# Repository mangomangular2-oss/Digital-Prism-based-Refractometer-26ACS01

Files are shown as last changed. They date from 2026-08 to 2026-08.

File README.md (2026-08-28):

# A Digital Prism-Based Refractometer

Firmware, CAD, raw data and analysis scripts for a low-cost automated
refractometer, built for the **Singapore Science Mentorship Programme 2026**
(Team 26ACS01).

The instrument measures a liquid's refractive index by finding the **critical
angle** at a prism–liquid interface. A stepper motor sweeps the prism through a
range of angles while a light-dependent resistor records how much light reaches
it; the critical angle is recovered from the steep edge of that signal, and
converted to refractive index on board.

**Team** — Isaac Yong Tze Hsi · Ng Yi-Shen · Shah Prish Vaishal \
**Mentor** — Mr Li Zhen, CRADLE, Science Centre Singapore\
**Teacher advisors** — Mdm Ali Basheera Banu, Mr Alvin Liew Shao Chuan\
**School** — Anglo-Chinese School (Independent), Singapore

## Headline results

| | |
|---|---|
| Mean deviation from reference values, five liquids | 0.18 % |
| Repeatability (standard error of five repeats, in *n*) | ±0.0005 |
| Total build cost | S$291 |
| Range | *n* = 1.000 – 1.498 (upper limit set by the prism's geometry and refractive index) |

## What is in this repository

| Folder | Contents |
|---|---|
| `firmware/` | The Arduino sketch that runs the instrument |
| `hardware/` | 3D-printable parts for the optical head and stage, as well as circuit schematic and total build cost |
| `data/` | Raw measurements, exactly as recorded |
| `analysis/` | Python scripts that turn the data into the paper's figures |
| `docs/` | The research paper and conference poster |

## Reproducing the figures

```bash
pip install numpy matplotlib openpyxl
cd analysis
python3 intensity_profile.py     # the sweep data, and the edge fit
python3 calibration.py           # measured vs accepted refractive index
python3 circuit_schematic.py     # wiring diagram, drawn from the pin map
```

## The main finding

Our first analysis took the **brightest point** of the light curve as the
critical angle. Checked against liquids of known refractive index, that was
wrong by up to 0.025.

The critical angle actually sits on the **steep rising edge** of the curve, at
the half-height point. Read there, the result is correct to 0.003 — about eight
times better. Where the brightest point falls depends on the beam width and the
sensor's position, so it shifts when the stage sweeps the other way; the steep
edge does not. `analysis/intensity_profile.py` shows both, for both sweep
directions.

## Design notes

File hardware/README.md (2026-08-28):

# Hardware

3D-printable parts for the optical head, rotating stage and housing.

Printed in black PLA. The colour matters, as it suppresses stray internal
reflections that otherwise produce false readings.

Circuit schematic for the final product, including an Arduino Uno Microcontroller, ULN2003 Driver Board, 16 x 2 LCD, 4 x 3 keypad, 28BYJ-48 Motor.

Complete bill of materials the final product.

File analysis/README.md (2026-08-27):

# Analysis

Scripts that regenerate the paper's figures from the raw data. Run them from
inside this folder — the data paths are relative.

```bash
pip install numpy matplotlib openpyxl
python3 intensity_profile.py
python3 calibration.py
python3 circuit_schematic.py
```

| Script | Output | What it does |
|---|---|---|
| `intensity_profile.py` | `intensity_profile.png` | Plots both sweep directions, fits the steep edge of each curve and marks the 50 % crossing taken as the critical angle |
| `calibration.py` | `calibration.png` | Measured against accepted refractive index, with the best-fit line and R² |
| `circuit_schematic.py` | `circuit_schematic.png` | Draws the wiring diagram directly from the firmware's pin map |

`intensity_profile.py` prints the recovered critical angle and refractive index
for each liquid and sweep direction, alongside the accepted value, so the
numbers in the paper can be checked against the raw data.

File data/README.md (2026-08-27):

# Data

Raw measurements, exactly as recorded. Nothing here has been corrected or
calibrated.

## `intensity_profiles.xlsx`

624 rows, one per motor half-step, covering a full sweep from a stage angle of
15°. This is the data behind the intensity-profile figure.

| Column | Meaning |
|---|---|
| `step` | Motor half-step number from the start of the sweep |
| `stage_angle_deg` | Stage angle, degrees. `15 + step x 0.0883` |
| `theta_hypotenuse_deg` | The corresponding angle at the prism–liquid interface |
| `A_water_counts` | Light sensor reading, deionised water, clockwise sweep |
| `A_olive_oil_counts` | Light sensor reading, olive oil, clockwise sweep |
| `B_water_counts` | Deionised water, anticlockwise sweep |
| `B_olive_oil_counts` | Olive oil, anticlockwise sweep |

Readings are raw 10-bit ADC counts (0–1023) from the LDR divider on A0.

The two sweep directions are the evidence for the main finding: the steep edge
of the curve lands in almost the same place either way, while the peak does not.

## `measurements.xlsx`

The trial-by-trial workbook behind the paper's tables.

| Sheet | Contents |
|---|---|
| `How to use` | Notes on filling the workbook |
| `T1 raw readings` | Every trial for the five reference liquids |
| `T1 summary` | Means and standard errors, all by formula |
| `T2 sucrose` | Concentration-mode trials, sucrose standards |
| `T3 bill of materials` | Costs, from receipts |
| `Conditions` | Instrument and session conditions |
| `Precision rules` | How many decimal places each quantity is reported to, and why |

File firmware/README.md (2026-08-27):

# Firmware

`refractometer.ino` — the sketch as flashed to the instrument. Arduino Uno.

## Libraries

Install through the Arduino IDE's Library Manager:

- **LiquidCrystal I2C** by Frank de Brabander
- **Keypad** by Mark Stanley / Alexander Brevig

## Pin map

| Pin | Use |
|---|---|
| D2 | MEASURE button (`INPUT_PULLUP`, pressed = LOW) |
| D3 | Mode rocker (`INPUT_PULLUP`, LOW = concentration mode) |
| D4–D7 | Keypad rows |
| D8–D11 | Stepper coils, via ULN2003 driver board |
| D12, D13 | Keypad columns 0, 1 |
| A0 | LDR (light-dependent resistor), in a divider with 10 kΩ |
| A1 | Keypad column 2 |
| A2 | Free |
| A3 | Free — reserved for a DS18B20 temperature sensor |
| A4, A5 | I²C to the LCD backpack (address 0x27) |

The 589 nm laser is powered from the 5 V rail and is not switched by the
microcontroller.

## Two modes

- **Rocker HIGH** — a single refractive-index measurement.
- **Rocker LOW** — calibration against standards of known concentration,
  then concentration readings for that solute.

## How the reading is taken

`findEdgeIndex()` is the core of it. After a sweep, it takes the samples lying
between 20 % and 80 % of the way from the dark level to the bright level,
least-squares fits a straight line through them, and solves that line for the
50 % crossing. That crossing is the critical angle, in units of motor steps.

One motor step is 0.0883°: the 28BYJ-48's real reduction is 63.68:1, not the
64:1 usually quoted, giving 4076 half-steps per revolution.

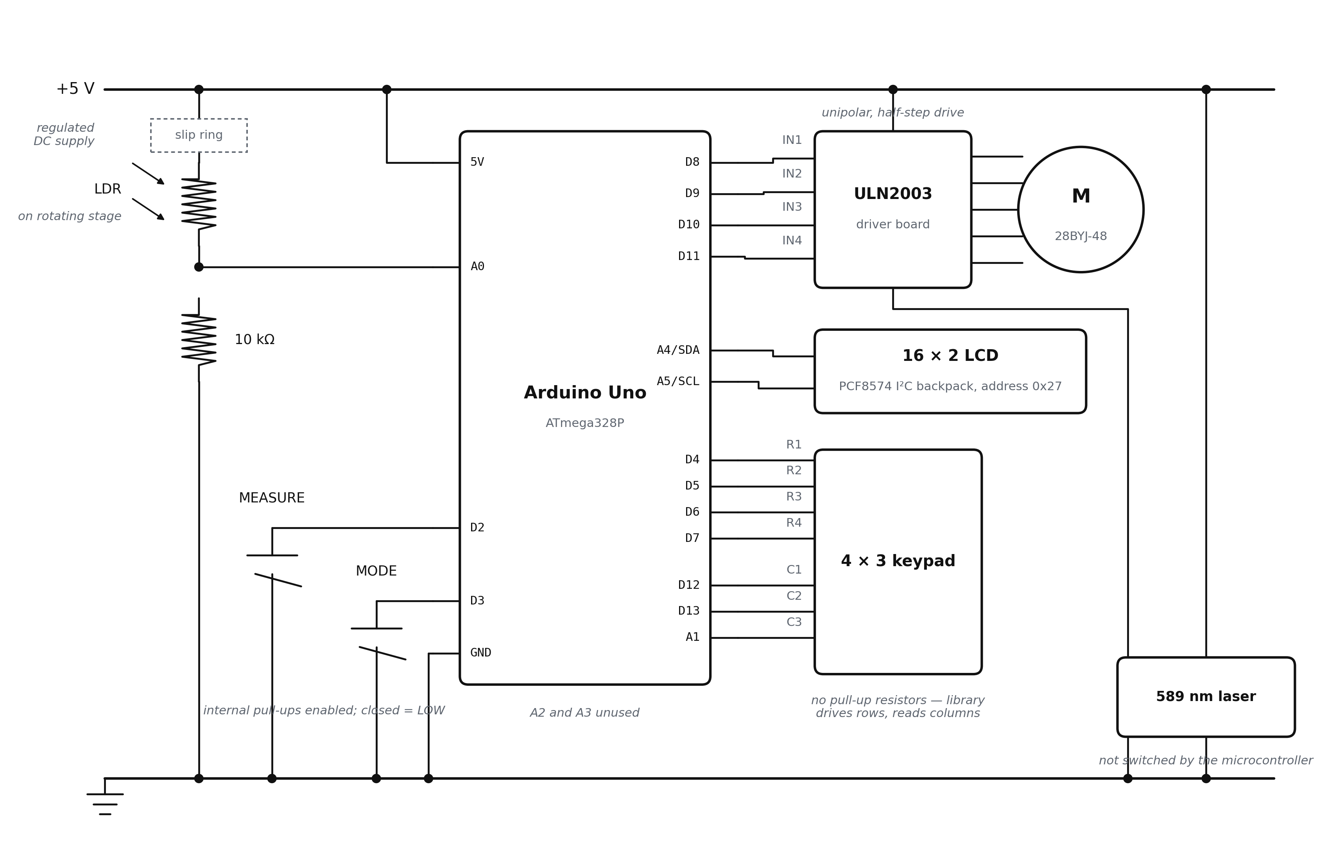
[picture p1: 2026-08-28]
hardware/Circuit Schematic.png

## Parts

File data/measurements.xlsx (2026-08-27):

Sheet: How to use
SMP 26ACS01 — Refractometer data collection
Fill only the YELLOW cells. Everything blue-grey is a formula — do not type over it.
WHAT TO RECORD PER TRIAL
The firmware prints one line per measurement over the serial link at 9600 baud:
steps=… angle=… incident=… case=… dark=… bright=… n=…
Copy 'angle', 'incident', 'case' and 'n' into the sheet. Five trials per liquid.
Empty, rinse and refill the cell between trials — otherwise you measure the same drop five times
and the standard error will be far smaller than the true repeatability.
Also copy the 'profile:' line for at least one trial per liquid. That array is Figure 4.
SHEETS
T1 raw readings 5 trials × 5 liquids. Computes mean, SD, standard error and % deviation.
T1 summary Table 1 exactly as it appears in the paper — copy this across.
T2 sucrose Concentration standards, 5 trials each, plus the hold-out test.
T3 bill of materials Component costs from receipts.
Conditions Dimensions, mass, temperature, prism index.
Precision rules How many decimal places each quantity may honestly carry.
THE ONE THING THAT MATTERS MOST
Five trials gives a standard error, but with n=5 that SE is itself uncertain by roughly ±35%.
Quote it to one significant figure and round the mean to match. Do not write 62.4531 ± 0.0087.

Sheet: T1 raw readings
Table 1 — raw readings, five trials per liquid
Yellow = type the value the firmware printed. Blue-grey = computed.
Liquid / trial | Stage angle φ /° | Incident α /° | Case (1 or 2) | n reported by device | θc computed /° | n check (1.50 sin θc)
Deionised water
trial 1
trial 2
trial 3
trial 4
trial 5
mean ± SE
SD / SE
Glucose solution (10%)
trial 1
trial 2
trial 3
trial 4
trial 5
mean ± SE
SD / SE
Sodium chloride solution (10%)
trial 1
trial 2
trial 3
trial 4
trial 5
mean ± SE
SD / SE
Glycerol solution (20% w/w)
trial 1
trial 2
trial 3
trial 4
trial 5
mean ± SE
SD / SE
Olive oil
trial 1
trial 2
trial 3
trial 4
trial 5
mean ± SE
SD / SE
SD = spread of the five trials (repeatability). SE = SD / √5 (uncertainty in the mean).

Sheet: T1 summary
Table 1 — as it should appear in the paper
All formulas. Nothing to type here.
Test liquid | Mean critical angle θc /° | Refractive index measured | Accepted refractive index | Deviation /%
Deionised water | ± |  | 1.3330
Glucose solution (10%) | ± |  | 1.3477
Sodium chloride solution (10%) | ± |  | 1.3505
Glycerol solution (20% w/w) | ± |  | 1.3600
Olive oil | ± |  | 1.4700
Mean deviation

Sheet: T2 sucrose
Table 2 — concentration mode
Five trials per standard. The last standard is the hold-out: measure it but do NOT use it in the fit.
Standard | Concentration /% w/w | n trial 1 | n trial 2 | n trial 3 | n trial 4 | n trial 5 | Mean n | SE | Use in fit?
Standard 1 |  |  |  |  |  |  |  |  | yes
Standard 2 |  |  |  |  |  |  |  |  | yes
Standard 3 |  |  |  |  |  |  |  |  | yes
Standard 4 |  |  |  |  |  |  |  |  | yes
Hold-out sample |  |  |  |  |  |  |  |  | no
Linear fit n = n₀ + k·c (standards 1–4 only)
gradient k
intercept n₀
R²
Hold-out test — the only independent check in the paper
true concentration /% w/w
concentration returned from fit
error /% w/w

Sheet: T3 bill of materials
Table 3 — bill of materials
From receipts only. If you cannot evidence a number, leave it blank rather than estimating.
Component | Quantity | Unit cost /S$ | Subtotal /S$ | Source / receipt
589 nm sodium laser
Right-angled isosceles prism
Stepper motor and ULN2003 driver
Slip ring
Arduino microcontroller
LDR, resistors and connecting wire
16×2 LCD display
Numeric keypad
Rocker switch
PLA filament (housing, stage, cell)
Total as built |  |  | 0.00
Commodity laser diode (replacement cost)
Total with commodity diode

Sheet: Conditions
Instrument and session details
Quantity | Value | Note
Number of trials per liquid | 5 | Fixed at 5 by your teacher's instruction
Room temperature /°C |  | Record with a thermometer; refractive index is temperature dependent
Device length /mm |  | Measure the finished direct-drive build, not the CAD model
Device width /mm
Device height /mm
Device mass /g |  | Kitchen scale is fine
Prism refractive index n_P | 1.50 | Used by every formula in this workbook. Change here if you measure it.
Steps per output revolution | 4076 | 28BYJ-48: 32 × 2 × 63.68395 = 4075.77
Degrees per step | 0.08832 | computed

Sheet: Precision rules
How many decimal places each quantity may honestly carry
Quantity | Report as | Why
Stage angle φ, incident α | 0.0001° | As printed by the firmware. Raw record only — do not quote in the paper.
Critical angle θc (mean) | match the SE | Round the mean to the same decimal place as its standard error.
Standard error on θc | 1 significant figure | With n = 5 the SE is itself uncertain by about ±35%; more digits are noise.
Refractive index, single trial | 0.00001 | What the device prints. Appendix A only.
Refractive index, mean | 0.0001 | One motor step ≈ 0.0007 in n, and the edge fit resolves below one step.
Refractive index — ACCURACY | 0.01 | Limited by n_P = 1.50 (3 s.f.). A 0.67% error there is ±0.009 in n.
Deviation from accepted value | 0.01 % | Supported only if the mean n is quoted to 4 d.p.
Accepted reference values | as published | Cite the source; do not add digits the reference does not have.
Concentration | 0.1 % w/w | Set by how accurately you can weigh and make up the standards.
Cost | 0.01 S$ | From receipts.
Dimensions | 1 mm (ruler) or 0.1 mm (calipers) | Match the instrument you actually used.
Temperature | 0.1 °C | If your thermometer reads to 0.1. Otherwise 1 °C.
THE DISTINCTION YOUR TEACHER IS PROBABLY TESTING
Precision (repeatability) is what the five trials show — the spread of your own readings.
Accuracy is how close you are to the true value, and it is capped by the assumed prism index.
You can legitimately quote a very repeatable mean to 4 d.p. while admitting the accuracy is only ±0.01.
Those are different claims and the paper must not blur them.

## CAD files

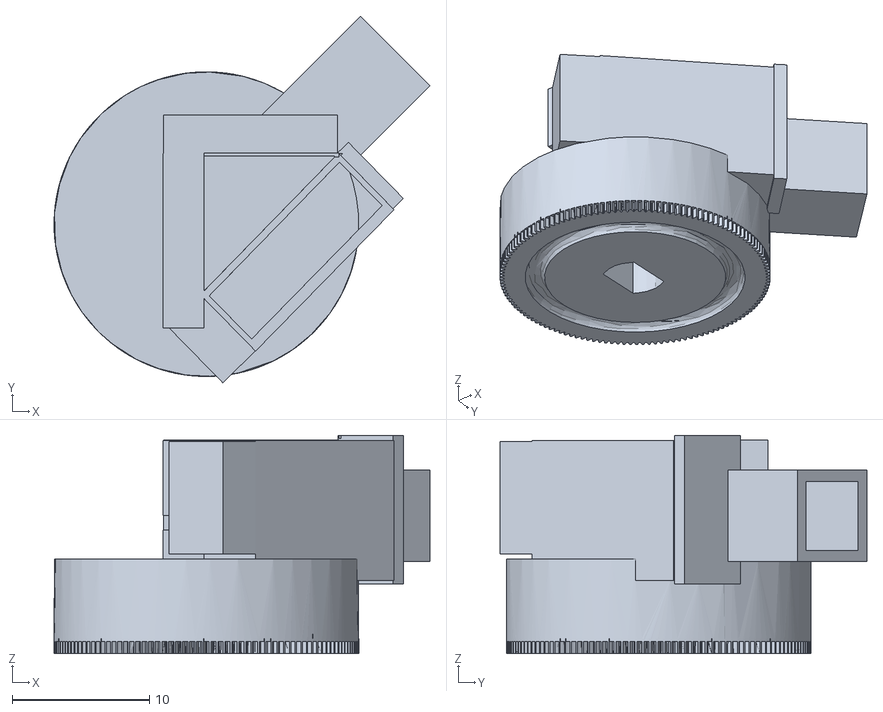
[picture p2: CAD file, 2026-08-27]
hardware/Prism Holder.stl
27.4 x 26.7 x 15.9

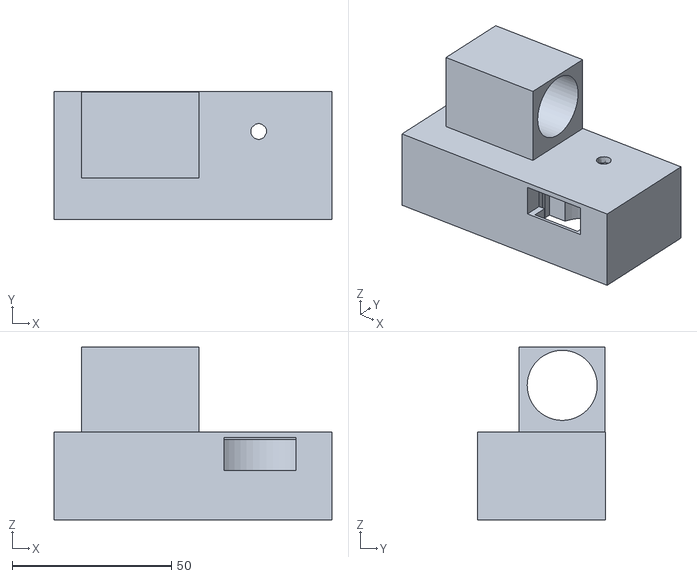
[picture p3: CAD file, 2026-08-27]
hardware/Motor and Laser Holder.stl
87.3 x 40.2 x 54.3

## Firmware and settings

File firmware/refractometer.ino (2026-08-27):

/* =====================================================================
   Portable prism refractometer  --  DIRECT DRIVE version
   Prism mounted straight onto the 28BYJ-48 output shaft (no gear stage).

   Mode 1 (rocker HIGH): single refractive-index measurement
   Mode 2 (rocker LOW) : calibration + concentration measurement

   Libraries (Library Manager):
     "LiquidCrystal I2C" by Frank de Brabander
     "Keypad" by Mark Stanley / Alexander Brevig
   ===================================================================== */

#include <Arduino.h>
#include <math.h>
#include <Wire.h>
#include <LiquidCrystal_I2C.h>
#include <Keypad.h>

/* --------------------------- pin map --------------------------------
   D0,D1   Serial
   D2      MEASURE button   (INPUT_PULLUP, pressed = LOW)
   D3      mode rocker      (INPUT_PULLUP, LOW = concentration mode)
   D4-D7   keypad rows
   D8-D11  stepper coils
   D12,D13 keypad cols 0,1
   A0      LDR
   A1      keypad col 2
   A2      FREE
   A3      FREE  <- reserve for DS18B20 temperature sensor
   A4,A5   I2C (LCD)
   -------------------------------------------------------------------- */

#define COIL1        8
#define COIL2        9
#define COIL3       10
#define COIL4       11
#define LDR_PIN     A0
#define SWITCH_PIN   3
#define BUTTON_PIN   2

LiquidCrystal_I2C lcd(0x27, 16, 2);   // try 0x3F if the screen stays blank

const byte ROWS = 4, COLS = 3;
char keyMap[ROWS][COLS] = {
  { '1', '2', '3' },
  { '4', '5', '6' },
  { '7', '8', '9' },
  { '*', '0', '#' }
};
byte rowPins[ROWS] = { 4, 5, 6, 7 };
byte colPins[COLS] = { 12, 13, A1 };
Keypad keypad = Keypad(makeKeymap(keyMap), rowPins, colPins, ROWS, COLS);

/* ------------------------ mechanical constants ----------------------
   DIRECT DRIVE: prism angle == motor output shaft angle.

   The 28BYJ-48's internal reduction is 63.68395:1, NOT 64:1, so a full
   output revolution is 32 * 2 * 63.68395 = 4075.77 half-steps, not 4096.
   VERIFY THIS ON YOUR UNIT: command 10 revolutions and see how far a mark
   on the prism drifts, then adjust.
   -------------------------------------------------------------------- */
const float STEPS_PER_REV     = 4076.0;
const float DEG_PER_STEP      = 360.0 / STEPS_PER_REV;      // ~0.08832 deg
const long  STEPS_PER_REV_L   = 4076L;
const long  MAX_TOTAL_STEPS   = 2L * STEPS_PER_REV_L;       // "two turns" budget

const unsigned int STEP_DELAY_US = 1500;
const float N_PRISM        = 1.500;    // measure/verify this
const float PRISM_APEX_DEG = 45.0;

/* ------------------------ optical constants ------------------------- */
const int  RISE_MARGIN     = 60;    // counts above dark that count as "light"
const int  MIN_CONTRAST    = 80;
const int  COARSE_STEP     = 4;
const int  BACKUP_STEPS    = 16;    // one back-off increment in stage 4b
const long MAX_BACKUP      = 400L;  // give up if the cell is THIS slow
const long SURVEY_LIMIT    = 120L;  // how far to look for a dark reference
const int  FINE_BACKUP     = 24;    // small, bounded run-up to the profiled edge
const int  LDR_RECOVER_MS  = 350;   // full settle after a reversal
const int  LDR_SETTLE_MS   = 60;    // settle per step during the fine creep
const byte PROFILE_MAX     = 48;    // samples recorded across the edge

int profile[PROFILE_MAX];

/* ------------------------ calibration store ------------------------- */
const byte MAX_CAL = 8;
const byte MIN_CAL = 3;

struct CalPoint { float conc; float n; };
CalPoint cal[MAX_CAL];
byte  calCount = 0;
float fitSlope = 0, fitIntercept = 0, fitR2 = 0, fitMaxErr = 0;
bool  fitValid = false;

/* ------------------------ motion state ------------------------------
   position is PURE physical bookkeeping: it tracks the rotor, one count
   per half-step, and is never negated or reset mid-motion. Travel is
   always computed as a difference against homePos.
   -------------------------------------------------------------------- */
long position     = 0;
long homePos      = 0;
long stepBudget   = 0;
bool budgetBlown  = false;

/* ------------------------ UI state ---------------------------------- */
enum AppState {
  ST_SINGLE_IDLE, ST_SINGLE_RESULT,
  ST_CAL_INPUT,   ST_CAL_MENU,    ST_CAL_PROMPT,  ST_CAL_RESULT,
  ST_TEST_IDLE,   ST_TEST_RESULT
};
AppState state = ST_SINGLE_IDLE;
bool concMode = false;

char  entryBuf[9];
byte  entryLen = 0;
float pendingConc = 0;

int lastButton = HIGH;
unsigned long lastButtonMs = 0;
const unsigned long DEBOUNCE_MS = 40;

enum MeasResult {
  M_OK, M_ERR_NO_DARK, M_ERR_NO_BRIGHT, M_ERR_NO_EDGE, M_ERR_RANGE, M_ERR_BUDGET
};

/* ===================================================================== */
/*  Low level                                                            */
/* ===================================================================== */

void Switch_function(int x) {
  switch (x & 7) {
    case 0: digitalWrite(COIL1, LOW);  digitalWrite(COIL2, LOW);  digitalWrite(COIL3, LOW);  digitalWrite(COIL4, HIGH); break;
    case 1: digitalWrite(COIL1, LOW);  digitalWrite(COIL2, LOW);  digitalWrite(COIL3, HIGH); digitalWrite(COIL4, HIGH); break;
    case 2: digitalWrite(COIL1, LOW);  digitalWrite(COIL2, LOW);  digitalWrite(COIL3, HIGH); digitalWrite(COIL4, LOW);  break;
    case 3: digitalWrite(COIL1, LOW);  digitalWrite(COIL2, HIGH); digitalWrite(COIL3, HIGH); digitalWrite(COIL4, LOW);  break;
    case 4: digitalWrite(COIL1, LOW);  digitalWrite(COIL2, HIGH); digitalWrite(COIL3, LOW);  digitalWrite(COIL4, LOW);  break;
    case 5: digitalWrite(COIL1, HIGH); digitalWrite(COIL2, HIGH); digitalWrite(COIL3, LOW);  digitalWrite(COIL4, LOW);  break;
    case 6: digitalWrite(COIL1, HIGH); digitalWrite(COIL2, LOW);  digitalWrite(COIL3, LOW);  digitalWrite(COIL4, LOW);  break;
    case 7: digitalWrite(COIL1, HIGH); digitalWrite(COIL2, LOW);  digitalWrite(COIL3, LOW);  digitalWrite(COIL4, HIGH); break;
  }
}

void coilsOff() {
  digitalWrite(COIL1, LOW); digitalWrite(COIL2, LOW);
  digitalWrite(COIL3, LOW); digitalWrite(COIL4, LOW);
}

/* Positive argument -> position decreases. Kept from the original sketch so
   "forward" still means the direction that sweeps toward loss of TIR.
   The step budget is enforced HERE, so no loop anywhere can run away.     */
void stepper(long steps) {
  long dir = (steps >= 0) ? -1 : 1;
  long n   = (steps >= 0) ?  steps : -steps;
  for (long i = 0; i < n; i++) {
    if (stepBudget <= 0) { budgetBlown = true; return; }
    stepBudget--;
    position += dir;
    Switch_function((int)(((position % 8) + 8) % 8));
    delayMicroseconds(STEP_DELAY_US);
  }
}

/* stepper(s) changes position by -s, so s = position - target */
void moveTo(long target) { stepper(position - target); }

/* Park at home unconditionally, even after the budget has been spent. */
void goHome() {
  stepBudget = MAX_TOTAL_STEPS * 2;
  moveTo(homePos);
  coilsOff();
}

int readLDR() {
  long s = 0;
  for (byte i = 0; i < 8; i++) { s += analogRead(LDR_PIN); delayMicroseconds(200); }
  return (int)(s >> 3);
}

/* ===================================================================== */
/*  Sub-step edge location                                               */
/*  Fits a line to the 20-80% portion of the falling edge and solves for  */
/*  the midpoint crossing. Returns a FRACTIONAL index into profile[].     */
/* ===================================================================== */

float findEdgeIndex(byte n, int dark, int bright, int threshold, bool *ok) {
  *ok = false;
  if (n < 2) return 0;

  float contrast = (float)(bright - dark);
  int hi = dark + (int)(0.80 * contrast);
  int lo = dark + (int)(0.20 * contrast);

  float sx = 0, sy = 0, sxx = 0, sxy = 0;
  byte m = 0;
  for (byte i = 0; i < n; i++) {
    if (profile[i] >= lo && profile[i] <= hi) {
      sx  += i;
      sy  += profile[i];
      sxx += (float)i * i;
      sxy += (float)i * profile[i];
      m++;
    }
  }

  if (m >= 3) {
    float d = (float)m * sxx - sx * sx;
    if (fabs(d) > 1e-6) {
      float a = ((float)m * sxy - sx * sy) / d;      // slope, counts per step
      float b = (sy - a * sx) / m;
      if (a < -0.5) {                                // must actually be falling
        *ok = true;
        return (threshold - b) / a;
      }
    }
  }

  /* Fallback: straight interpolation between the two bracketing samples. */
  for (byte i = 1; i < n; i++) {
    if (profile[i - 1] >= threshold && profile[i] < threshold) {
      float den = (float)(profile[i - 1] - profile[i]);
      *ok = true;
      if (den > 0.5) return (float)(i - 1) + (float)(profile[i - 1] - threshold) / den;
      return (float)i;
    }
  }
  return 0;
}

/* ===================================================================== */
/*  Measurement                                                          */
/* ===================================================================== */

MeasResult measureRefractive(float *nOut, float *angleOut) {
  goHome();
  delay(200);

  stepBudget  = MAX_TOTAL_STEPS;      // safeguard: two output revolutions
  budgetBlown = false;

  /* 1. Learn the dark reference. Back off (negative direction) until the
        reading stops falling. This works whether we start inside the TIR
        band or outside it, and it means every approach to the edge comes
        from the same side so backlash is taken up identically.
        No absolute light level is assumed anywhere.                       */
  int  v0 = readLDR();
  int  darkLevel = v0, maxSeen = v0;
  long back = 0;
  bool sawFall = false;
  int  flat = 0;
  while (back < MAX_BACKUP && !budgetBlown) {
    stepper(-COARSE_STEP);
    back += COARSE_STEP;
    delay(LDR_SETTLE_MS);
    int v = readLDR();
    if (v > maxSeen)   maxSeen   = v;
    if (v < darkLevel) darkLevel = v;
    if (maxSeen - darkLevel >= MIN_CONTRAST) sawFall = true;
    if (v <= darkLevel + RISE_MARGIN / 2) flat++; else flat = 0;
    if (sawFall && flat >= 3)               break;   // clearly out of the band
    if (!sawFall && back >= SURVEY_LIMIT)   break;   // looks like we began dark
  }
  if (budgetBlown) { goHome(); return M_ERR_NO_DARK; }
  delay(LDR_RECOVER_MS);
  if (readLDR() < darkLevel) darkLevel = readLDR();

  /* 2. Coarse sweep forward until the light rises clearly above dark.
        The trip point is relative, so it works at any LED brightness.     */
  int trip = darkLevel + RISE_MARGIN;
  while (readLDR() < trip && !budgetBlown) stepper(COARSE_STEP);
  if (budgetBlown) { goHome(); return M_ERR_NO_BRIGHT; }

  /* 3. Move deeper into the band and let the cell settle, so brightLevel
        is the true plateau rather than a lagging value.                   */
  stepper(COARSE_STEP * 3);
  delay(LDR_RECOVER_MS);
  int brightLevel = readLDR();
  if (brightLevel - darkLevel < MIN_CONTRAST) { goHome(); return M_ERR_NO_EDGE; }
  int threshold = (brightLevel + darkLevel) / 2;

  /* 4a. Fast coarse sweep to the far edge. The LDR lags at this speed, so
         this only gets us close.                                          */
  while (readLDR() >= threshold && !budgetBlown) stepper(COARSE_STEP);
  if (budgetBlown) { goHome(); return M_ERR_NO_EDGE; }

  /* 4b. Reverse back into the band until the cell genuinely reads bright
         again. A slow photocell lags tens of steps behind at coarse speed,
         so this MUST be a loop -- a fixed back-off silently fails.        */
  long backed = 0;
  while (backed < MAX_BACKUP && !budgetBlown) {
    stepper(-BACKUP_STEPS);
    backed += BACKUP_STEPS;
    delay(LDR_RECOVER_MS);
    if (readLDR() >= threshold) break;
  }
  if (readLDR() < threshold || budgetBlown) { goHome(); return M_ERR_NO_EDGE; }

  /* 4c. Settled coarse approach. Waiting at every step removes the lag, so
         this ends within COARSE_STEP of the true edge.                     */
  long guard4 = 0;
  bool nearEdge = false;
  while (guard4 < backed + 6L * COARSE_STEP && !budgetBlown) {
    stepper(COARSE_STEP);
    guard4 += COARSE_STEP;
    delay(LDR_SETTLE_MS);
    if (readLDR() < threshold) { nearEdge = true; break; }
  }
  if (!nearEdge || budgetBlown) { goHome(); return budgetBlown ? M_ERR_BUDGET : M_ERR_NO_EDGE; }

  /* 4d. Small bounded run-up so the profile always fits in PROFILE_MAX. */
  long fineBack = FINE_BACKUP;
  stepper(-fineBack);
  delay(LDR_RECOVER_MS);
  while (readLDR() < threshold && fineBack < (long)PROFILE_MAX - 10 && !budgetBlown) {
    stepper(-8); fineBack += 8; delay(LDR_RECOVER_MS);
  }
  if (readLDR() < threshold || budgetBlown) { goHome(); return M_ERR_NO_EDGE; }

  /* 4c. Creep forward one step at a time, recording the whole profile.
         profile[i] is taken at position (creepStart - i).                 */
  long creepStart = position;
  int  lowCut     = darkLevel + (brightLevel - darkLevel) / 5;   // 20%
  byte np = 0;
  bool crossed = false;

  while (np < PROFILE_MAX) {
    if (np > 0) { stepper(1); if (budgetBlown) break; }
    delay(LDR_SETTLE_MS);
    profile[np] = readLDR();
    np++;
    if (profile[np - 1] < lowCut) { crossed = true; break; }
  }
  if (!crossed || budgetBlown) { goHome(); return budgetBlown ? M_ERR_BUDGET : M_ERR_NO_EDGE; }

  /* Dump the profile so you can check how many steps the transition spans.
     If it spans 1 step, interpolation buys you nothing and you need gears. */
  Serial.print(F("profile:"));
  for (byte i = 0; i < np; i++) { Serial.print(' '); Serial.print(profile[i]); }
  Serial.println();

  bool edgeOk;
  float idx = findEdgeIndex(np, darkLevel, brightLevel, threshold, &edgeOk);
  if (!edgeOk) { goHome(); return M_ERR_NO_EDGE; }

  /* 5. Geometry, in fractional steps. */
  float edgePos    = (float)creepStart - idx;
  float sweepSteps = (float)homePos - edgePos;              // positive
  sweepSteps = fmod(sweepSteps, STEPS_PER_REV);
  if (sweepSteps < 0) sweepSteps += STEPS_PER_REV;

  float bigAngle = sweepSteps * DEG_PER_STEP;               // 0 .. 360 deg
  float incident = 90.0 - bigAngle;
  int   caseNum  = (incident < 0) ? 1 : 2;
  incident = fabs(incident);

  float s = sin(incident * DEG_TO_RAD) / N_PRISM;
  if (s > 1.0 || s < -1.0) { goHome(); return M_ERR_RANGE; }

  float thetaR = asin(s);
  float apex   = PRISM_APEX_DEG * DEG_TO_RAD;
  float n      = N_PRISM * sin((caseNum == 1) ? (apex - thetaR) : (apex + thetaR));

  *angleOut = bigAngle;
  *nOut     = n;

  Serial.print(F("steps=")); Serial.print(sweepSteps, 3);
  Serial.print(F("  angle=")); Serial.print(bigAngle, 4);
  Serial.print(F("  incident=")); Serial.print(incident, 4);
  Serial.print(F("  case=")); Serial.print(caseNum);
  Serial.print(F("  dark=")); Serial.print(darkLevel);
  Serial.print(F("  bright=")); Serial.print(brightLevel);
  Serial.print(F("  n=")); Serial.println(n, 5);

  goHome();
  return M_OK;
}

/* ===================================================================== */
/*  Least squares:  n = slope * conc + intercept                         */
/* ===================================================================== */

bool fitLine() {
  fitValid = false;
  if (calCount < 2) return false;

  float mx = 0, my = 0;
  for (byte i = 0; i < calCount; i++) { mx += cal[i].conc; my += cal[i].n; }
  mx /= calCount; my /= calCount;

  float sxx = 0, sxy = 0, syy = 0;
  for (byte i = 0; i < calCount; i++) {
    float dx = cal[i].conc - mx;
    float dy = cal[i].n    - my;
    sxx += dx * dx; sxy += dx * dy; syy += dy * dy;
  }
  if (sxx < 1e-12) return false;

  fitSlope     = sxy / sxx;
  fitIntercept = my - fitSlope * mx;
  fitR2        = (syy > 1e-12) ? (sxy * sxy) / (sxx * syy) : 1.0;
  fitValid     = (fabs(fitSlope) > 1e-9);

  /* Worst residual expressed in concentration units. Far more informative
     than R2, which stays above 0.99 even for a badly wrong point.         */
  fitMaxErr = 0;
  if (fitValid) {
    for (byte i = 0; i < calCount; i++) {
      float e = fabs(cal[i].n - (fitSlope * cal[i].conc + fitIntercept)) / fabs(fitSlope);
      if (e > fitMaxErr) fitMaxErr = e;
    }
  }
  return fitValid;
}

float concFromN(float n) { return (n - fitIntercept) / fitSlope; }
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
void loop() {
  static bool lastRocker = false;
  static unsigned long rockerMs = 0;
  bool rocker = (digitalRead(SWITCH_PIN) == LOW);
  if (rocker != lastRocker && millis() - rockerMs > DEBOUNCE_MS) {
    lastRocker = rocker;
    rockerMs   = millis();
    enterMode(rocker);
    return;
  }

  /* k    = a key that was just pressed
     kHold = a key that has just been held down past the hold time         */
  char k = 0, kHold = 0;
  if (keypad.getKeys()) {
    for (byte i = 0; i < LIST_MAX; i++) {
      if (keypad.key[i].stateChanged) {
        if      (keypad.key[i].kstate == PRESSED) k     = keypad.key[i].kchar;
        else if (keypad.key[i].kstate == HOLD)    kHold = keypad.key[i].kchar;
      }
    }
  }

  bool  btn = buttonPressed();
  float n, angle;
  char  line[17];

  switch (state) {

    /* ---------------- MODE 1 : single measurement ------------------ */
    case ST_SINGLE_IDLE:
      if (btn) {
        lcd2("Measuring...", "please wait");
        MeasResult r = measureRefractive(&n, &angle);
        if (r != M_OK) { showError(r); lcd2("SINGLE MODE", "Press MEASURE"); }
        else {
          lcd.clear();
          lcd.setCursor(0, 0); lcd.print(F("n = ")); lcd.print(n, 4);
          lcd.setCursor(0, 1); lcd.print(F("ang ")); lcd.print(angle, 2);
          lcd.print((char)223);
          state = ST_SINGLE_RESULT;
        }
      }
      break;

    case ST_SINGLE_RESULT:
      if (btn || k) { state = ST_SINGLE_IDLE; lcd2("SINGLE MODE", "Press MEASURE"); }
      break;

    /* ---------------- MODE 2 : concentration ----------------------- */
    case ST_CAL_INPUT:
      if (kHold == '*') { entryLen = 0; showEntry(); break; }   // hold * = clear
      if (k) {
        if (k >= '0' && k <= '9') {
          if (entryLen < 7) { entryBuf[entryLen++] = k; showEntry(); }
        } else if (k == '*') {
          bool hasDot = false;
          for (byte i = 0; i < entryLen; i++) if (entryBuf[i] == '.') hasDot = true;
          if (!hasDot && entryLen < 7) { entryBuf[entryLen++] = '.'; showEntry(); }
        } else if (k == '#') {
          if (entryLen == 0) { state = ST_CAL_MENU; showMenu(); break; }
          if (calCount >= MAX_CAL) {
            lcd2("Store full", "# then 1 to fit"); delay(1800); showEntry(); break;
          }
          entryBuf[entryLen] = '\0';
          pendingConc = atof(entryBuf);
          entryLen = 0;
          state = ST_CAL_PROMPT;
          lcd.clear();
          lcd.setCursor(0, 0);  lcd.print(F("Clean+load std"));
          lcd.setCursor(0, 1);  lcd.print(F("C=")); lcd.print(pendingConc, 3);
          lcd.setCursor(10, 1); lcd.print(F("*=bck"));
        }
      }
      break;

    case ST_CAL_MENU:
      if (k == '1') {                                   // fit and enter test mode
        if (calCount >= MIN_CAL && fitLine()) {
          lcd.clear();
          lcd.setCursor(0, 0); lcd.print(F("Cal done  n=")); lcd.print(calCount);
          lcd.setCursor(0, 1);
          lcd.print(F("R2=")); lcd.print(fitR2, 4);
          lcd.print(F(" e=")); lcd.print(fitMaxErr, 2);
          delay(2500);
          state = ST_TEST_IDLE;
          lcd2("TEST MODE", "MEASURE  #=menu");
        } else {
          snprintf(line, sizeof(line), "Need %d points", MIN_CAL);
          lcd2("Not enough data", line); delay(1800); showMenu();
        }
      } else if (k == '2') {                            // delete last point
        if (calCount) { calCount--; fitLine(); lcd2("Last point", "deleted"); }
        else          { lcd2("Nothing to", "delete"); }
        delay(1300); showMenu();
      } else if (k == '3') {                            // wipe calibration
        calCount = 0; fitValid = false; entryLen = 0;
        lcd2("Calibration", "cleared"); delay(1400);
        state = ST_CAL_INPUT; showEntry();
      } else if (k) {                                   // anything else = back
        state = ST_CAL_INPUT; showEntry();
      }
      break;

    case ST_CAL_PROMPT:
      if (k == '*') { state = ST_CAL_INPUT; showEntry(); break; }
      if (btn) {
        lcd2("Measuring...", "please wait");
        MeasResult r = measureRefractive(&n, &angle);
        if (r != M_OK) { showError(r); state = ST_CAL_INPUT; showEntry(); }
        else {
          cal[calCount].conc = pendingConc;
          cal[calCount].n    = n;
          calCount++;
          fitLine();
          lcd.clear();
          lcd.setCursor(0, 0);
          lcd.print(F("P")); lcd.print(calCount);
          lcd.print(F(" n=")); lcd.print(n, 4);
          lcd.setCursor(0, 1);
          if (calCount >= 3 && fitValid) {
            lcd.print(F("R2=")); lcd.print(fitR2, 4);
            lcd.print(F(" e=")); lcd.print(fitMaxErr, 2);
          }
          else                           { lcd.print(F("stored")); }
          state = ST_CAL_RESULT;
        }
      }
      break;

    case ST_CAL_RESULT:
      if (btn || k) { state = ST_CAL_INPUT; showEntry(); }
      break;

    case ST_TEST_IDLE:
      if (k == '#') { state = ST_CAL_MENU; showMenu(); break; }
      if (btn) {
        lcd2("Measuring...", "please wait");
        MeasResult r = measureRefractive(&n, &angle);
        if (r != M_OK) { showError(r); lcd2("TEST MODE", "MEASURE  #=menu"); }
        else {
          float c = concFromN(n);
          float lo, hi; calRange(&lo, &hi);
          lcd.clear();
          lcd.setCursor(0, 0); lcd.print(F("C = ")); lcd.print(c, 3);
          if (c < lo || c > hi) lcd.print(F(" !"));
          lcd.setCursor(0, 1); lcd.print(F("n=")); lcd.print(n, 4);
          lcd.print(F(" R2=")); lcd.print(fitR2, 3);
          Serial.print(F("conc=")); Serial.println(c, 5);
          state = ST_TEST_RESULT;
        }
      }
      break;

    case ST_TEST_RESULT:
      if (k == '#') { state = ST_CAL_MENU; showMenu(); break; }
      if (btn || k) { state = ST_TEST_IDLE; lcd2("TEST MODE", "MEASURE  #=menu"); }
      break;
  }
}

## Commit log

2026-08-28 Update README to include hardware details
    Added circuit schematic details for the final product.
2026-08-28 Update README with bill of materials
    Added a complete bill of materials for the final product.
2026-08-28 Renaming of cad subdirectory to include hardware
    [Motor and Laser Holder.stl, Prism Holder.stl]
2026-08-28 Renaming of Circuit Schematic
